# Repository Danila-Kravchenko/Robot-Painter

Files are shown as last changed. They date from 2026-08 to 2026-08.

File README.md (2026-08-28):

# Робот-художник

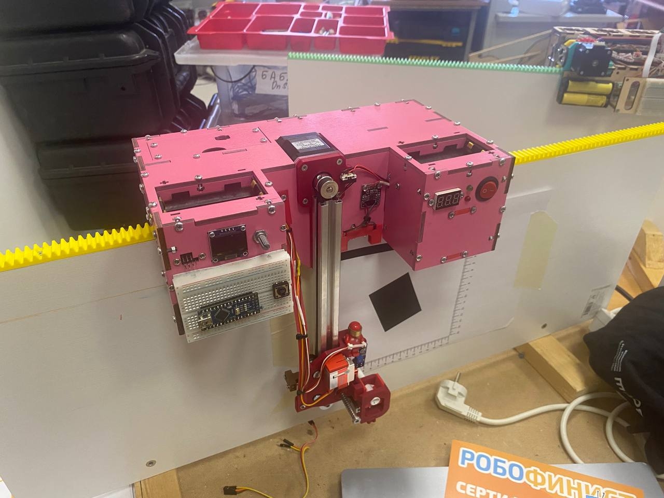
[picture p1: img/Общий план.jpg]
общий план


Робот выполнен в соответствии с **единым техническим заданием** ([ЕТЗ]("https://robot.mipt.ru/uchastnikam/reglament/etz_info/")) Всероссийской олимпиады школьников по информатике в профиле робототехника. Основые критерии ЕТЗ:
* **Задача робота** - нанесение изображений в плоскостей осей Х и У
* **Рабочая область** - лист А4, закрепленный на полигоне. Начало координат - пересечение черных линий, расположенных в левом и верхнем краях листа
* **Размеры** - 300х300х300 мм
* **Скорость** - 100 мм/с
* **Автономность** - полное отсутствие подключения внешних проводных и беспроводных компонентов
* **Погрешность позиционирования** - не более 3 мм
* **Рабочий инструмент** - маркер диаметром 8-18 мм и длиной 120-180 мм
* **Самостоятельная разработка** - запрещается использование готовые специализированных решений для 3Д-принтеров, ЧПУ-станков и т.п.
* **Интерфейс** - возможность выбирать 1 из 10 заданий, предложенных организаторами, а также наличие светодиодов индикации: зеленого и красного
* **Плата коммутации с штырьевыми разъемами:** - наличие макетной платы не менее 400 точек для подключения внешних устройств, а также разъемов с питанием 5В, интерфейсом UART, цифровыми и аналоговым входами 

---

## Аппаратная архитектура

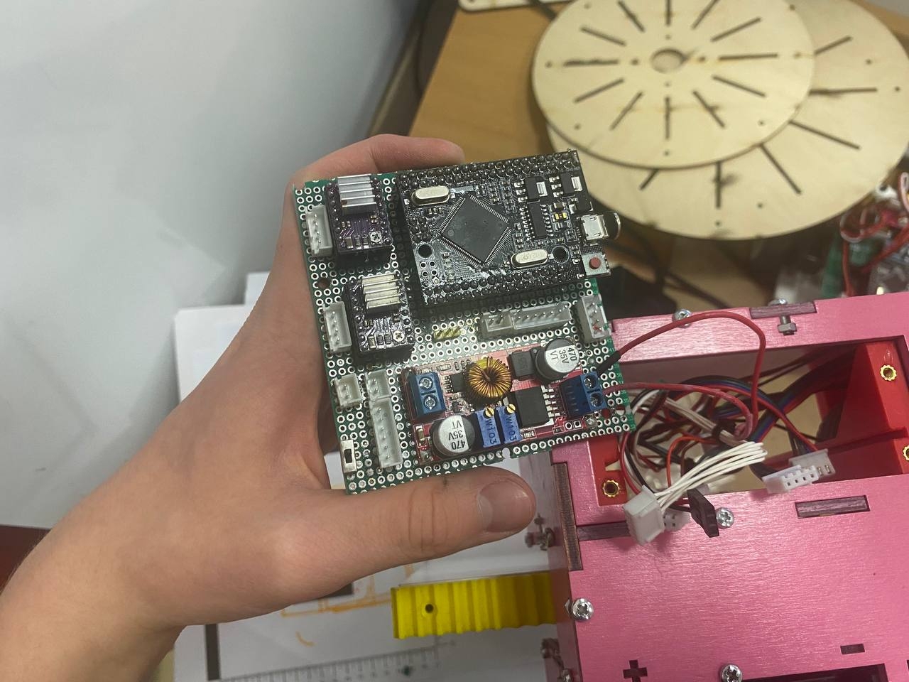
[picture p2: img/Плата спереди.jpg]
Плата спереди


### Контроллер
* Arduino Mega 2560 Pro.

### Датчики и сенсоры
* **Контроль заряда** - цифровой мультиметр 0-100В
* **Определение начала координат** - TCRT5000
* **Калибровка плоттера:**
    * Установка в 0 по У - концевой выключатель
    * Нахождение кончика маркера - ktir0911s

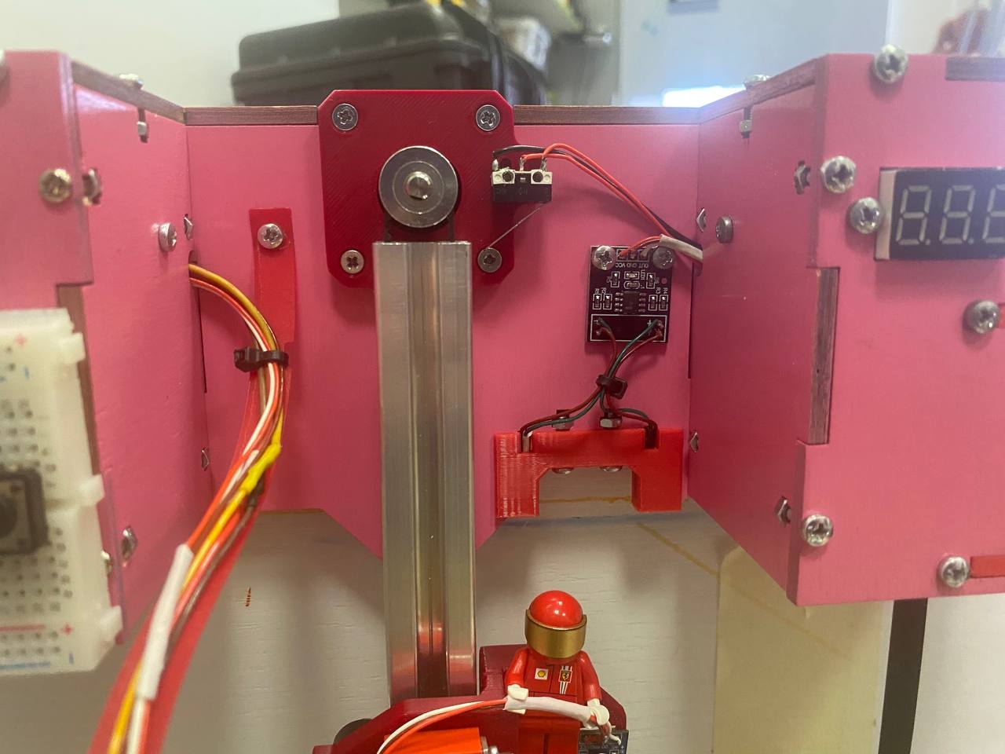
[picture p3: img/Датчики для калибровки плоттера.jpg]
Датчики для калибровки плоттера


### Интерфейс
* **Световая индикация** - красный и зеленый светодиоды
* **Отображение информации** - OLED дисплей 128х64 на чипе SSD1306
* **Выбор команды** - поворотный энкодер EC11

Интерфейс

### Разъемы
* **UART** - использование логического конвертора для подключения устройств, толерантных к 3.3В

### Исполнительные устройства
* **Моторы** 2 шаговых двигателя Nema 17 17HS8401.
* **Драйверы управления двигателями** DRV8825.
* **Плоттер** сервопривод подъёма маркера — HV2006MG;

### Система питания
* **Источник питания** - сборка 4S1P из Li-ion аккумуляторов 18650, 3000 мА·ч.
* **Распределение питания:**
    * шаговые двигатели — 16 В (напрямую от батареи);
    * сервоприводы — 7 В от стабилизатора XL4015;
    * контроллер — 16 В (напрямую от батареи) на пин Vin;
    * цифровой вольтметр — 16 В (напрямую от батареи);
    * логический конвертор - 3.3 В от пина 3.3V контроллера.
    * остальная периферия — 5 В от пина 5V контроллера.

---

## Конструкция и механика

* **Корпус** - лазерная резка из фанеры 4 мм. Сборка выполнена по системе «шип-паз» с механической фиксацией винтами.
* **Крепление к полигону** - 3 пластиковых колеса с шинами конструктора лего, а также опорная и ведущая шестерни
* **Ось У:**
    * **Плоттер:**
        * Крепление маркера - пластиковая прижамная деталь, регулируемая винтом с пластиковой накатанной головкой
        * Прижим маркера - кривошипно-кулачковый механизм для защиты от передавливания на пишущую поверхность
        
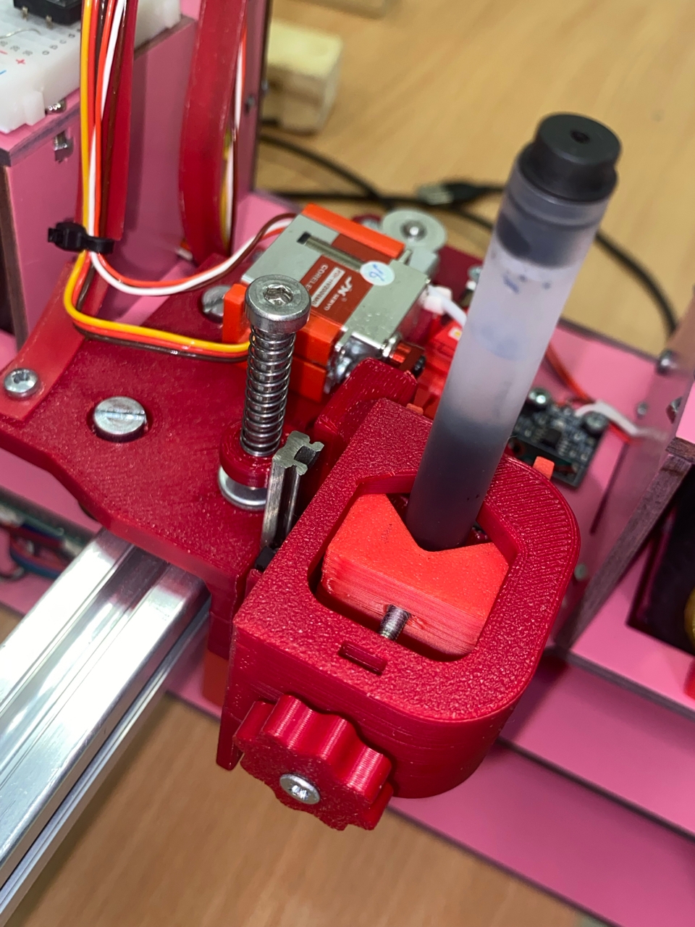
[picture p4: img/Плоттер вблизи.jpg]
Плоттер_вблизи
        

        * Крепление к V-образному профилю - 3 ролика с подвижной фиксацией
        * Крепление зубчатого ремня - подвижный фиксатор для контроля натяжения

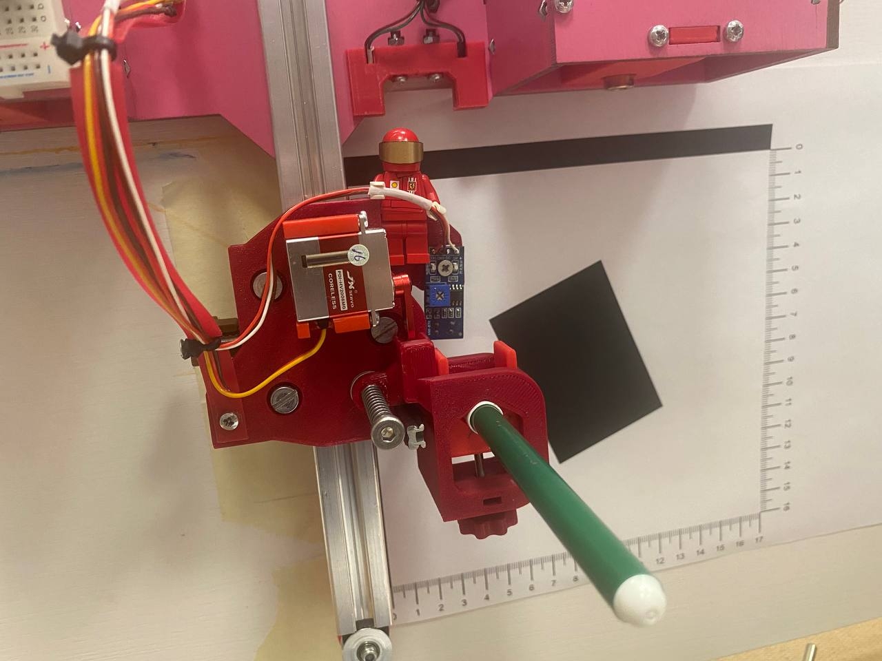
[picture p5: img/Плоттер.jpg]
Плоттер
        

    * **V-образный профиль** - перемещение плоттера
    * **Опорный ролик на профиле**
* **Выдвижная плата** - пластиковые крепления с пазами, а также съемная крышка над платой

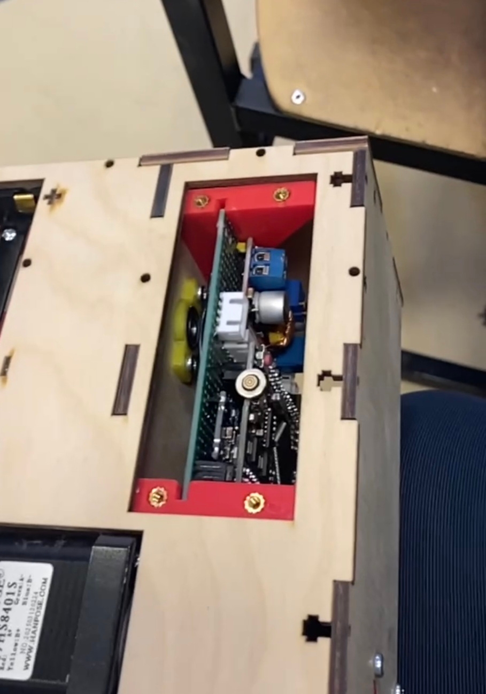
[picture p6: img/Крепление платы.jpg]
Крепление платы


---

## Алгоритмы и логика управления

В проекте реализована гибридная система траекторного управления, оптимизированная для работы с шаговыми двигателями (ШД) в координатах XY. Алгоритм разделен на два ключевых режима: линейное перемещение и криволинейное позиционирование.

### 1. Линейное перемещение

Режим предназначен для точной прорисовки прямых линий с контролируемой динамикой движения.

*   **Получение скоростей:**
    *   Результирующий вектор желаемой скорости $\vec{V}$ раскладывается на проекции по осям координат ($V_x$ и $V_y$).
    *   Для сохранения геометрии отрезка составляется жесткая пропорция скоростей на основе соотношения приращений координат:
        $$\frac{V_x}{V_y} = \frac{\Delta X}{\Delta Y}$$
    *   Расчет абсолютных значений базовых скоростей выполняется через тригонометрический базис и теорему Пифагора:
        $$V = \sqrt{V_x^2 + V_y^2}$$
*   **Защита от пропуска шагов ШД:**
    *   Интегрирован алгоритм плавного разгона и замедления (рампа скорости) с заданным предельным ускорением $a$.
    *   Во избежание перекоса осей и динамических ударов, мгновенное ускорение по каждой из осей ($a_x, a_y$) рассчитывается строго пропорционально текущей целевой скорости этой оси.
*   **Профиль скорости (Регулятор):**
    *   Реализован пропорциональный регулятор (**П-регулятор**) обратной связи по расстоянию до конечной точки.
    *   Введено ограничение управляющего воздействия (насыщение) на уровне максимальной технологической скорости ($V_{max}$).
    *   **Динамика движения:** График ускорения представляет собой наклонную прямую (линейное нарастание момента), а фаза замедления рассчитывается по экспоненциальному закону для мягкого подхода к целевой точке без перерегулирования.

### 2. Криволинейное перемещение

Режим используется для быстрого позиционирования инструмента по криволинейным траекториям.

*   **Траекторная логика:** Осуществляет перевод рабочего органа из текущей точки в заданную координату по сложной (сглаженной) траектории.
*   **Ограничение динамики:** Перемещение выполняется на фиксированной **минимальной скорости** ($V_{min}$) и **без ускорения** ($a = 0$). Такой подход гарантирует отсутствие вибраций конструкции при резкой смене направления движения инструмента во время холостых переходов.

---

## Структура ПО
* `etz_main.ino` — главный файл;
* `drivers.ino` — низкоуровневые функции управления роботом (управление моторами, перемещение в точку и т.п.);
* `move.ino` — высокоуровневые функции управления роботом (прорисовка фигур);
* `tasks.ino` — пустые функции для выполнения заданий;
* `interface.ino` — работа интерфейса: выбор задания, отображение информации о задании и т.п.;
* `ports.ino` — функции для обработки разъемов
* `hello_kitty.ino` — массив для отображения изображения

---

## Сборка и запуск

### Комплектующие и материалы

**Электронные комплектующие**

| Группа | Наименование | Модель / номинал | Кол-во | Назначение |
|---|---|---|:---:|---|
| Контроллер | Микроконтроллер | Arduino Mega 2560 Pro | 1 | Главное вычислительное ядро |
| Приводы | Шаговый двигатель | Nema 17 17HS8401 | 2 | Движение и балансировка |
| Приводы | Драйвер ШД | DRV8825 | 2 | Управление фазами ШД |
| Приводы | Сервопривод | HV2006MG | 1 | Прижим маркера |
| Сенсоры | Цифровой вольтметр | DC 0-100 V | 1 | Контроль заряда |
| Сенсоры | Концевой выключатель | 1А, 125В | 1 | Калибровка оси у |
| Сенсоры | Оптопара | TCRT5000 | 1 | Следование по линии |
| Сенсоры | Лазерный концевик | ktir0991s | 1 | Нахождение кончика маркера |
| Интерфейс | Поворотный энкодер | EC11 | 1 | Выбор режима |
| Интерфейс | Дисплей | OLED display 128x64 | 1 | Выбор режима |
| Интерфейс | Светодиоды | Красный и зеленые цвета, 5 мм | 1 | Отображение состояния |
| Разъемы | Конвертер уровней | Logic level converter 3.3V - 5V | 1 | Подключение устройств, толерантных к 3.3В |
| Питание | Аккумулятор | Li-ion 18650, 3000 мА·ч | 4 | Сборка 4S1P |
| Питание | SMD-холдер аккумуляторов | 2 × 18650 | 2 | Монтаж и коммутация АКБ |
| Питание | Тумблер | Ø 3 мм | 1 | Коммутация питания |
| Питание | DC-DC преобразователь | XL4015 | 1 | Шины 6 В |
| Обвязка | Конденсатор электролитический | 100 мкФ, 25 В | 2 | Сглаживание пульсаций по питанию драйверов |
| Обвязка | Резистор | 220 Ом | 2 | Токоограничение светодиодов |
| Монтаж | Плата макетная паячная | 9 × 15 см | 1 | Монтаж электроники |

**Механические комплектующие и материалы**

| Группа | Наименование | Модель / номинал | Кол-во | Назначение |
|---|---|---|:---:|---|
| Рама | Профиль конструкционный | 20×20 L | 1 (0,24 м) | Элемент несущей конструкции |
| Рама | Фанера берёзовая | 4 мм | — | Несущие панели рамы (лазерная резка) |
| 3D-печать | Пластик для 3D-печати | ABS / PETG / PLA | — | Колёса, плоттер, шестерни и крепежные детали |
| Механика | Миниатюрные подшипники | 5x14x5 мм | 20 шт. | Подшипниковые узлы колёс и осей |
| Механика | Муфта фланцевая жёсткая | Ø 5 мм | 2 | Соединение вала с шестернями |
| Механика | Вал линейный хромированный | Ø 5 мм, 100 мм | 4 | Опорные шестерня и колеса |
| Механика | Стопорные кольца | для втулок осей Ø 5 мм | 8 | Фиксация подшипников и втулок |
| Механика | Шкив | Perlin для Ender3 V2 | 3 | Крепление плоттера на профиле |
| Механика | Рельса и каретка | MGN7C, 50 мм | 1 | Кривошипно-кулачковы механизм |
| Механика | Пружина | 30 мм, Ø 5-8 мм | 1 | Кривошипно-кулачковы механизм |
| Механика | Зубчатый ремень | GT2-20 | 600 мм | Перемещние плоттера |
| Механика | Зубчатый шкив | GT2-20, Ø отверстия 5 мм | 1 | Перемещние плоттера |
| Механика | Зубчатый шкив с подшипником | GT2-20, Ø отверстия 5 мм, 20 зубьев | 1 | Перемещние плоттера |
| Механика | Лего шина | Артикул 41897 (56x28 мм) | 1 | Крепление к полигону |
| Крепёж | Винт М4 с неполной резьбой | М4, 5 мм - резьба; Ø 5 мм, 30 мм - нерезьбовая часть | 1 | Напрвляющая для пружины |
| Крепёж | Винты и гайки | M3 | набор | Механическая фиксация узлов |
| Крепёж | Винты и гайки | M5, 25 мм | 3 шт. | Механическая фиксация узлов |
| Крепёж | Вплавляемые гайки | M3 | набор | Механическая фиксация печатных деталей |
| Крепёж | Вплавляемые гайки | M4 | 1 шт. | Крепление винта с неполной резьбой |
| Расходники | Стяжка нейлоновая | — | набор | Кабель-менеджмент |

### Необходимое ПО
* Arduino IDE 2.0;
* библиотеки (устанавливаются через менеджер библиотек):
    * [Adafruit_SSD1306](https://github.com/adafruit/Adafruit_SSD1306.git);
    * [Adafruit_GFX](https://github.com/adafruit/Adafruit-GFX-Library.git);
    * [TimerOne](https://github.com/PaulStoffregen/TimerOne.git);
    * [TimerThree](https://github.com/PaulStoffregen/TimerThree.git).
* Скетч находится в папке `firmware/etz_main/`.

### Подключение

| Пин Arduino | Тип | Назначение | Примечание |
|---|-----|---|---|
| 4 | Цифровой | `MOTOR_DIR_Y` — направление ШД по оси у| |
| 5 | Цифровой | `MOTOR_STEP_Y` — шаг ШД по оси у | Аппаратный таймер Timer3 |
| 11 | Цифровой | `MOTOR_STEP_X` — шаг ШД по оси х | Аппаратный таймер Timer1 |
| 12 | Цифровой | `MOTOR_DIR_X` — направление ШД по оси х | |
| 9 | PWM | `CLAWS_PIN` — сервопривод клешней | |
| 2 | Цифровой | `ENCODER_PIN1` — первый канал поворотного энкодера | |
| 6 | Цифровой | `ENCODER_PIN2` — второй канал поворотного энкодера | |
| 3 | Цифровой | `BUTTON_PIN` — тактовая кнопка поворотного энкодера | |
| 27 | Цифровой | `GREEN_LED` — индикация батареи | Через резистор 220 Ом |
| 29 | Цифровой | `RED_LED` — индикация состояния | Через резистор 220 Ом |
| 25 | Цифровой | `KTIR_PIN` — лазерный концевой выключатель | нахождение кончика маркера |
| 23 | Цифровой | `END_BUTTON` — концевой выключатель | калибровка по оси у |
| 24 | Цифровой | `D_PIN` — цифровой разъем коммутационной платы | |
| A5 | Аналоговый | `A_PIN` — аналоговый разъем коммутационной платы | |
| 14 (TX3) | UART | `Serial3` — разъем-UART коммутационной платы | |
| 15 (RX3) | UART | `Serial3` — разъем-UART коммутационной платы | |
| A0 | Аналоговый | `LINE_SENSOR` — TCRT5000 | нахождение начала координат |

### Порядок запуска
1. **Инициализация:** включите робота и установите маркер в прижимной механизм на расстоянии 2-3 мм от поверхности. Нажмите кнопку на поворотном энкодере для продолжения
2. **Калибровка:** плоттер начнет определение абсолютного нуля по оси у, затем определит положение кончика маркера и сохранит знаение. После отображения интерфейса на дисплее калибровка считается законченной
3. **Определение начала координат:** единократно и автоматически запускается при выборе задачи. Для калибровки датчика света установите робота таким образом, чтобы маркер находился ровно на правой границе черной вертикальной линии. Запустите задачу `calibr` (в самом низу списка): робот откалибрует датчик освещенности и сразу определит начало координат (в дальнейшем проверок не будет)
3. **Старт:** установите указатель на дисплее на нужную задачу и нажмите на ручку поворотного энкодера 

---

## Демонстрация

Сердечко

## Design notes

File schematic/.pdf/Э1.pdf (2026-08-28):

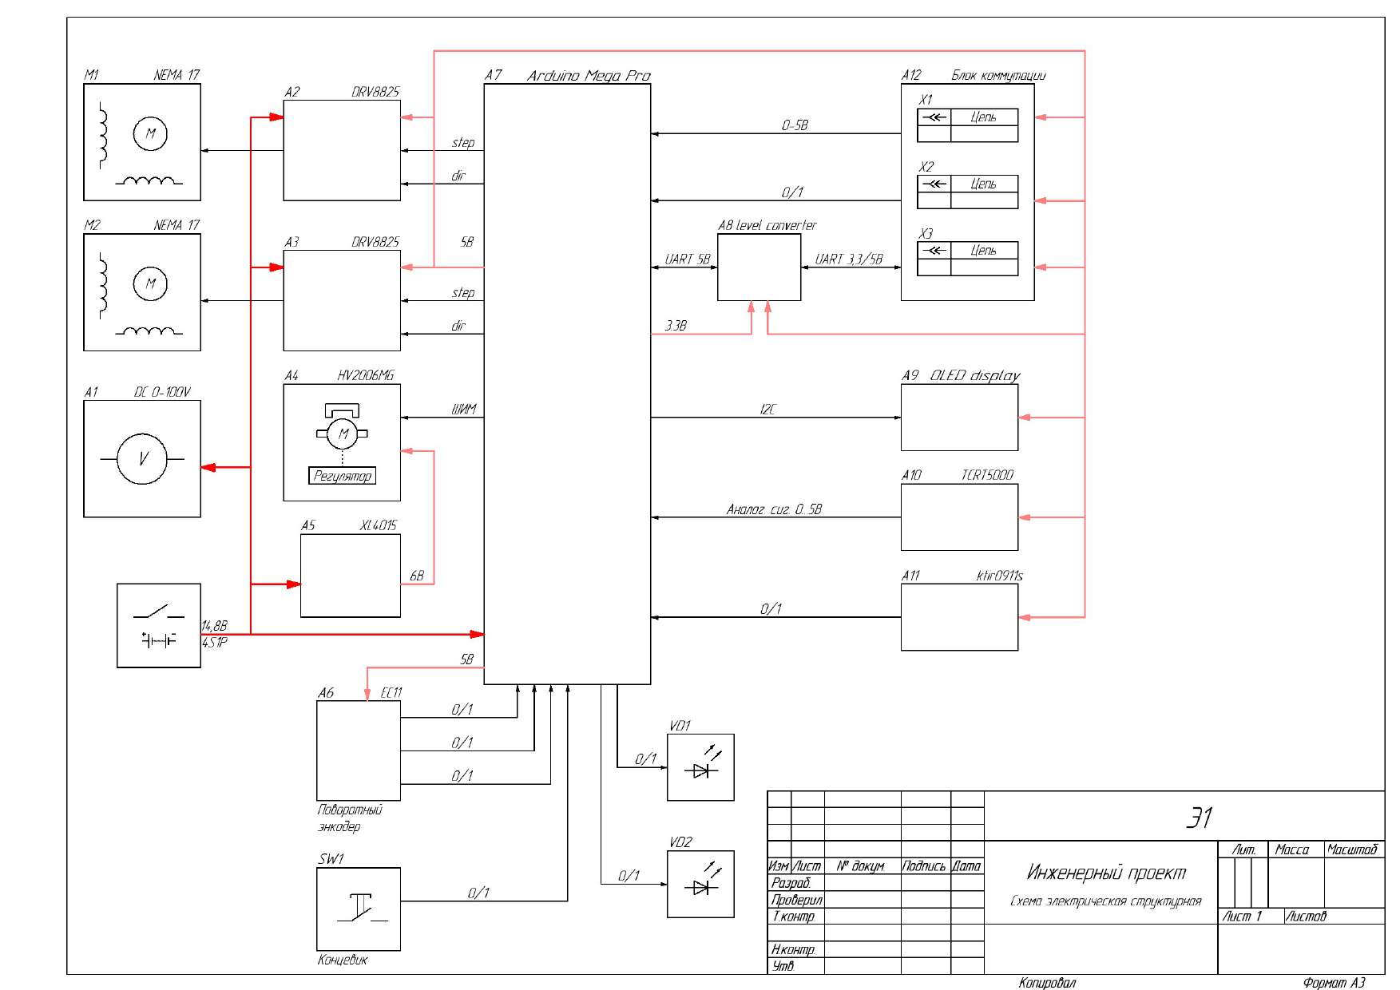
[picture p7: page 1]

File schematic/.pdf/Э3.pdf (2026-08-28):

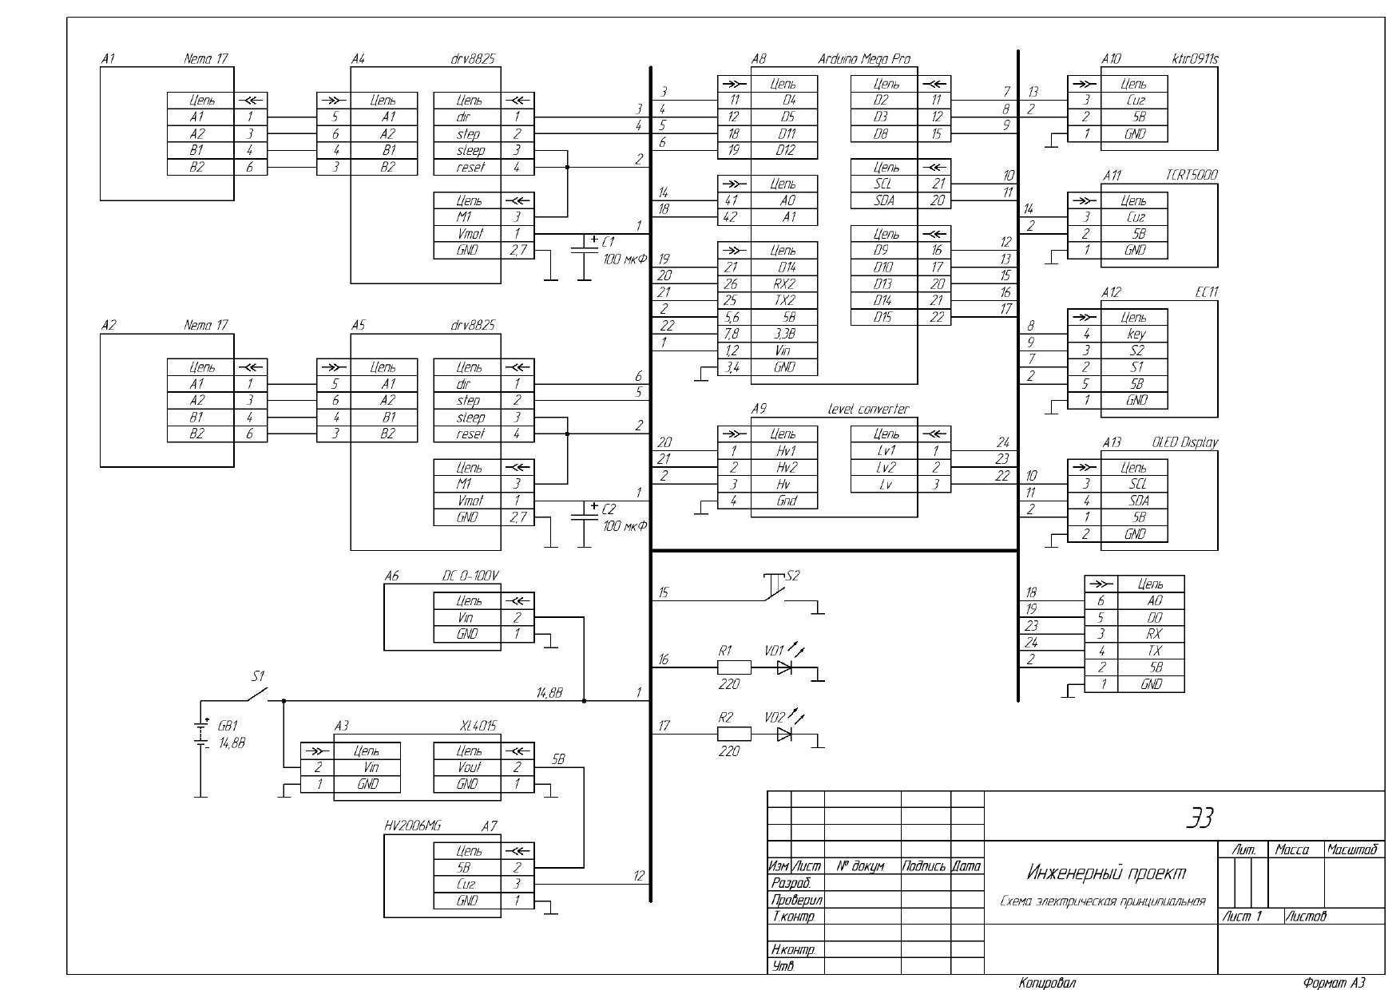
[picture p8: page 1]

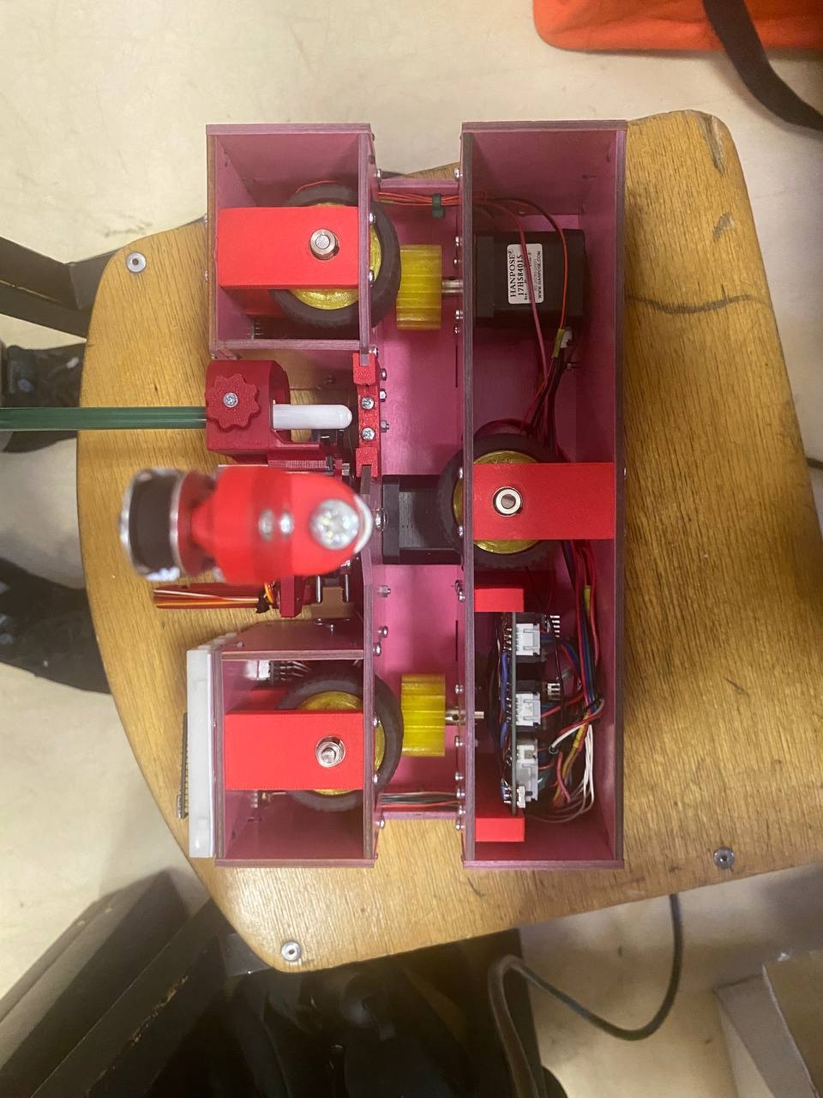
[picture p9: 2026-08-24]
img/Вид снизу.jpg

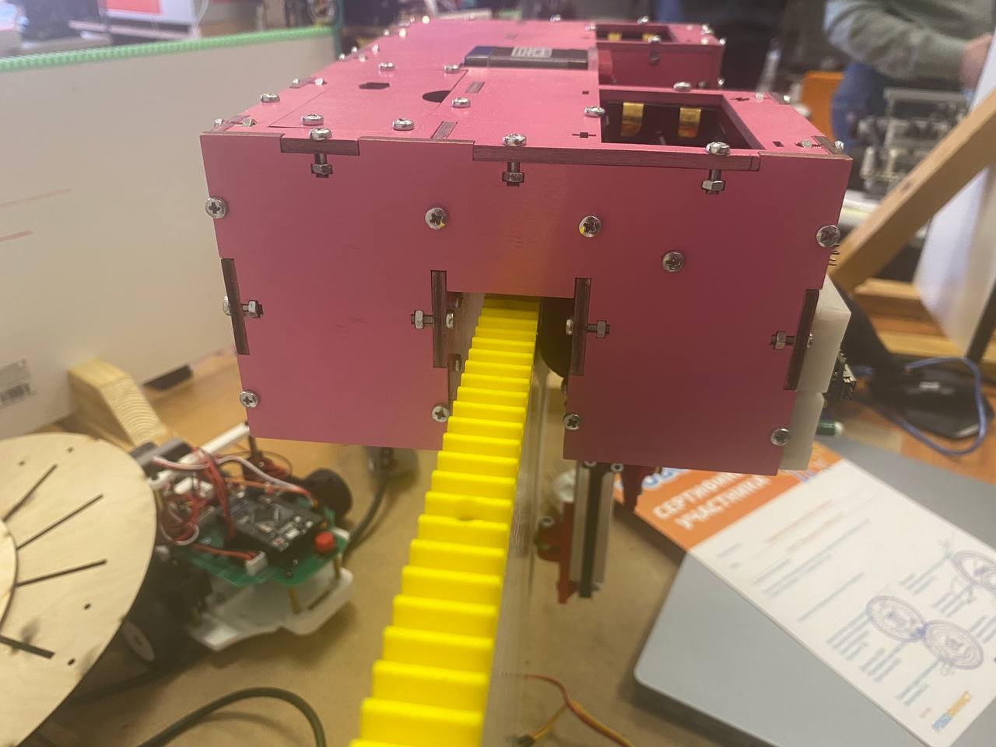
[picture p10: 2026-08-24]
img/Вид сбоку.jpg

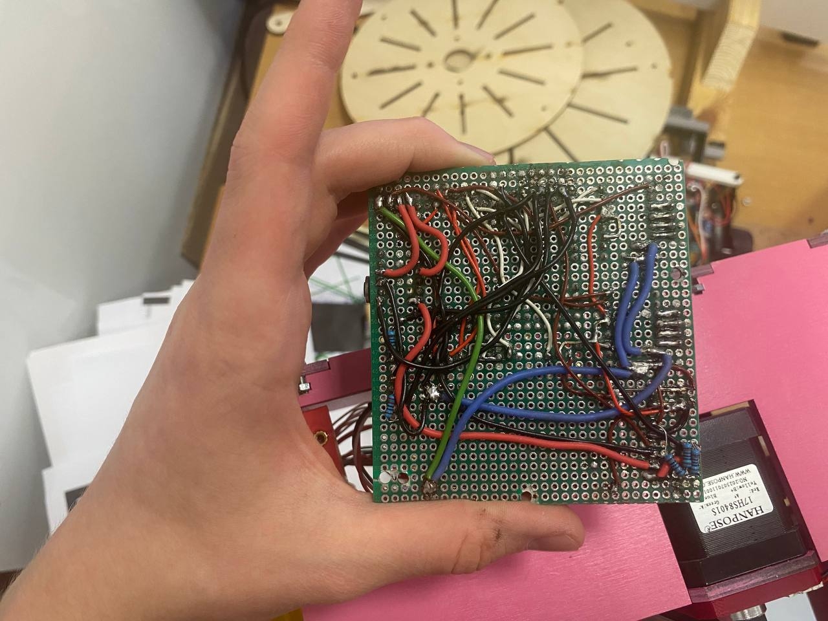
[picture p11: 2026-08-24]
img/Плата сзади.jpg

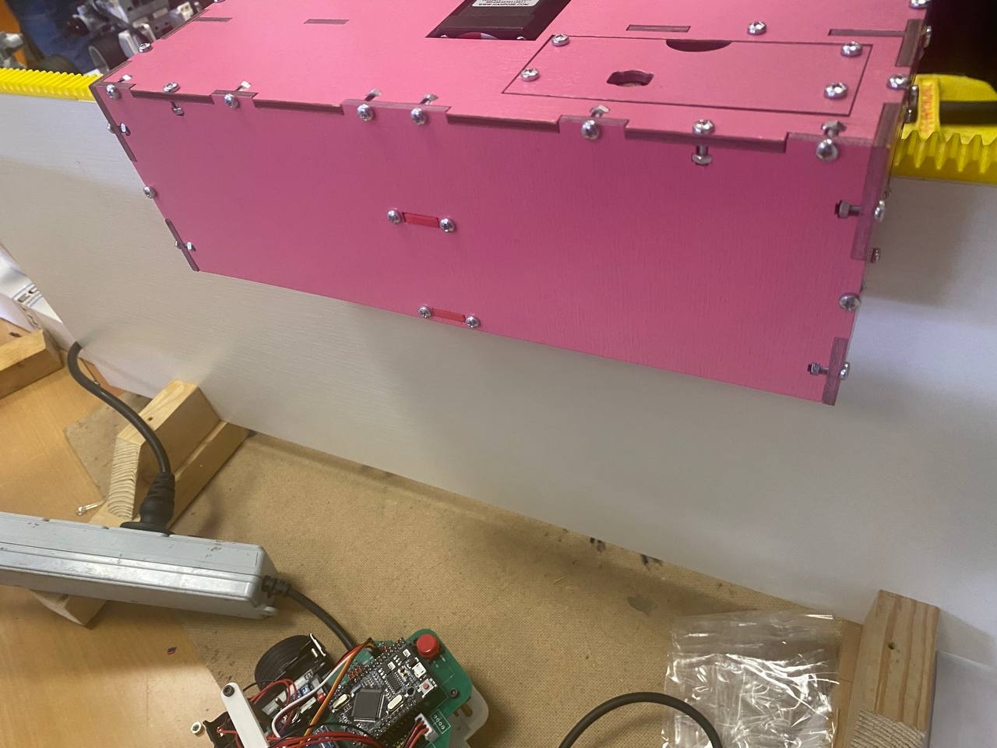
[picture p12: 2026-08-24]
img/Вид сзади.jpg

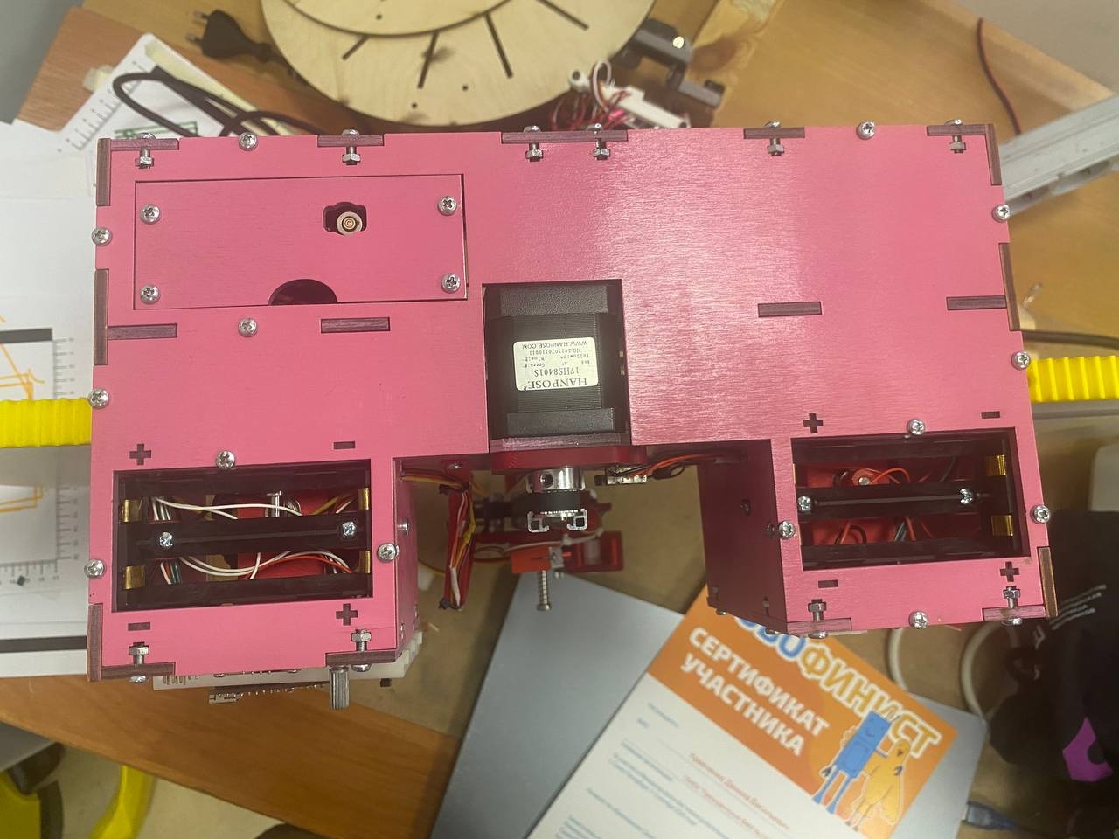
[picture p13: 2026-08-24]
img/Вид сверху.jpg

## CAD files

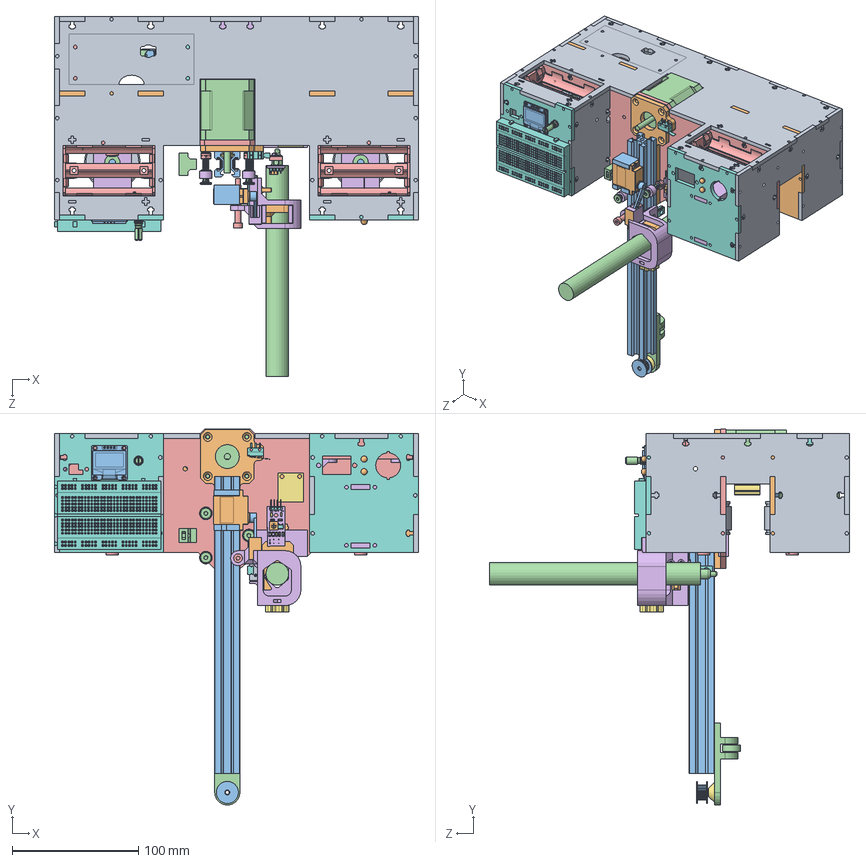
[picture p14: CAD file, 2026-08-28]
mechanics/3d model/робот_закл.SLDASM
288.0 x 297.4 x 285.0 mm
задняя стенка справа
передняя стенка справа
крепление шаговика новое
motor_17hs8401 x 2
передняя стенка слева
корпус ктира
плата под ктир
лицевая стенка
боковая правая стенка с лицевой стороны x 2
переходник для профиля
профиль
MVG-P4 x 3
MVG-P6 x 3
MVG-P3 x 3
MVG-P2 x 3
рельса
каретка для рельс
hv2006mg
Microservo horn
зажим ремня
TCRT5000
leds Geometry
pin
IC_smd_8
smd_10k Geometry x 2
cover x 2
smd_150 Geometry
cover2
Surf Geometry x 2
cover3 x 2
LED_SMD x 2
smd_1k Geometry x 2
cover4 x 2
pot Geometry
pin2
leds2 Geometry
pins
Board Geometry
TXT
4PinsOut Geometry
pin3
крепление сервы
фломастер
винт для каретки
крепление фломастера
Деталь1
концевик
колесо x 6
заглушка для колеса x 3
ось для колес x 3
подшипник x 9
стопорное кольцо x 5
крепление колес x 6
шестеренка новая x 2
втулка x 2
крепление подшипников x 2
ось для шестерни
шестерня для ремня на ось
крепление ролика
аккумуляторный отсек x 2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

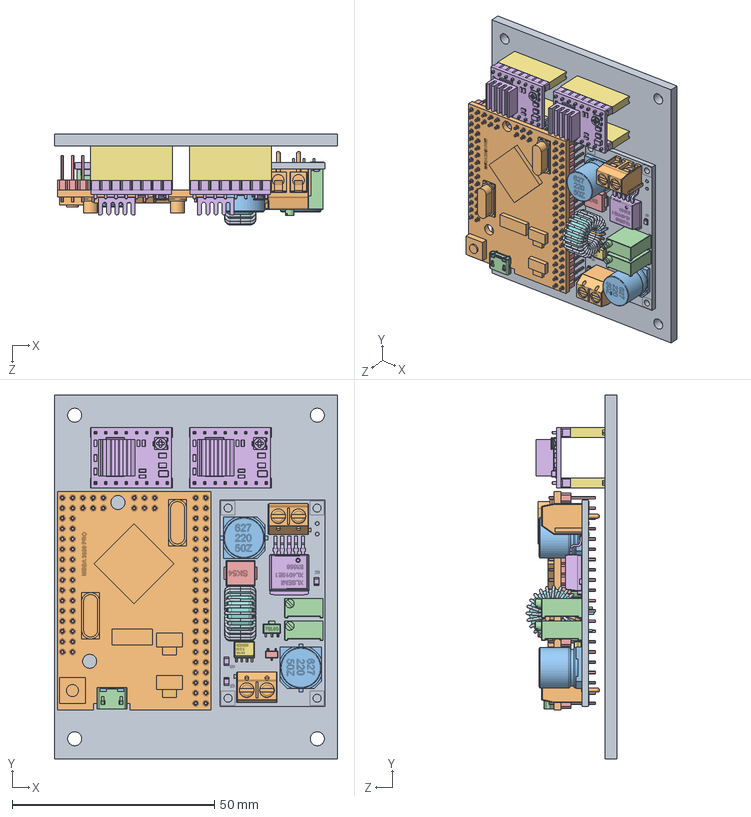
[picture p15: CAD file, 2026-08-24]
mechanics/3d model/плата.SLDASM
70.0 x 90.0 x 22.5 mm
плата
_X2_04100440043404430438043D043E_X0_ _X2_043C043504330430_X0_ __X2_0441_X0_ _X2_043D043E0436043A0430043C0438_X0_
_X2_043D043E0436043A0430_X0_ x 86
Driver DRV8825 x 2
PBS-8 x 4
kicad_module_3D_MINI560 PCB
Basetta
DG301-5.0-02 v1 x 2
CAPACITOR 10x10 SMD v1 x 2
Trimpot 3296W v1 x 2
DO-214AB v1
XL4015 TO263-5-1 v1
LM358 SOIC08 v1
Toro
Spira x 22
SpiraCodA
SpiraCpdB
UPC78L08T-E1-AZ
SC-59A v1
LED v1 x 3

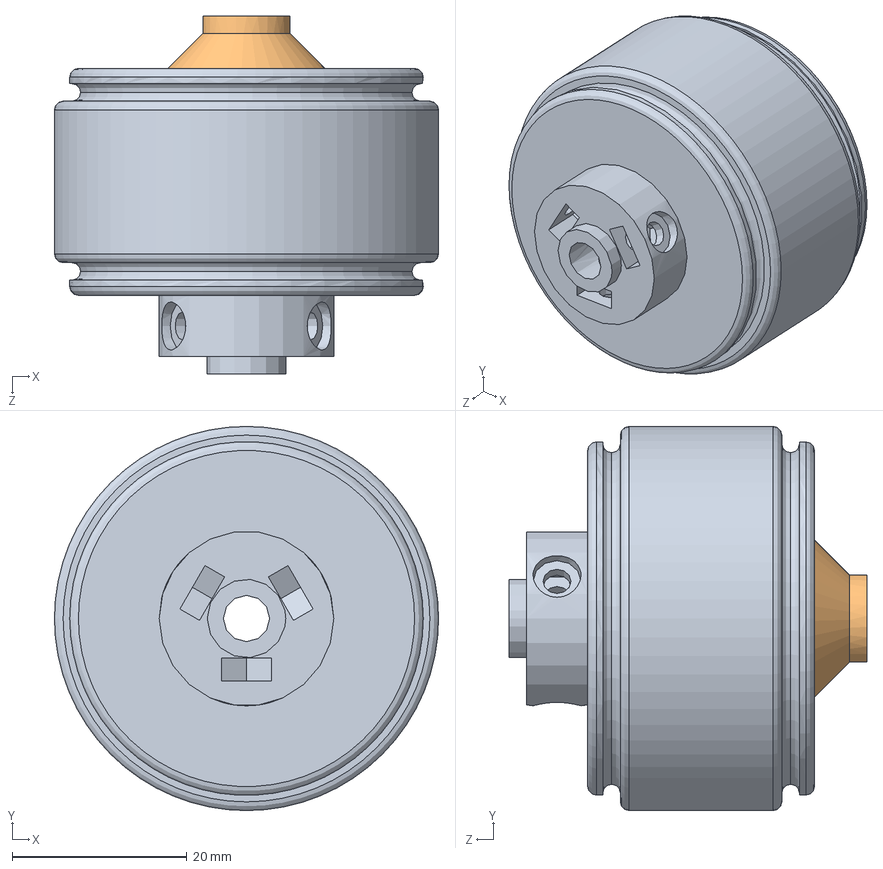
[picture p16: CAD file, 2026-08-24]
mechanics/3d model/колесо.SLDASM
44.0 x 44.0 x 41.0 mm
колесо
заглушка для колеса

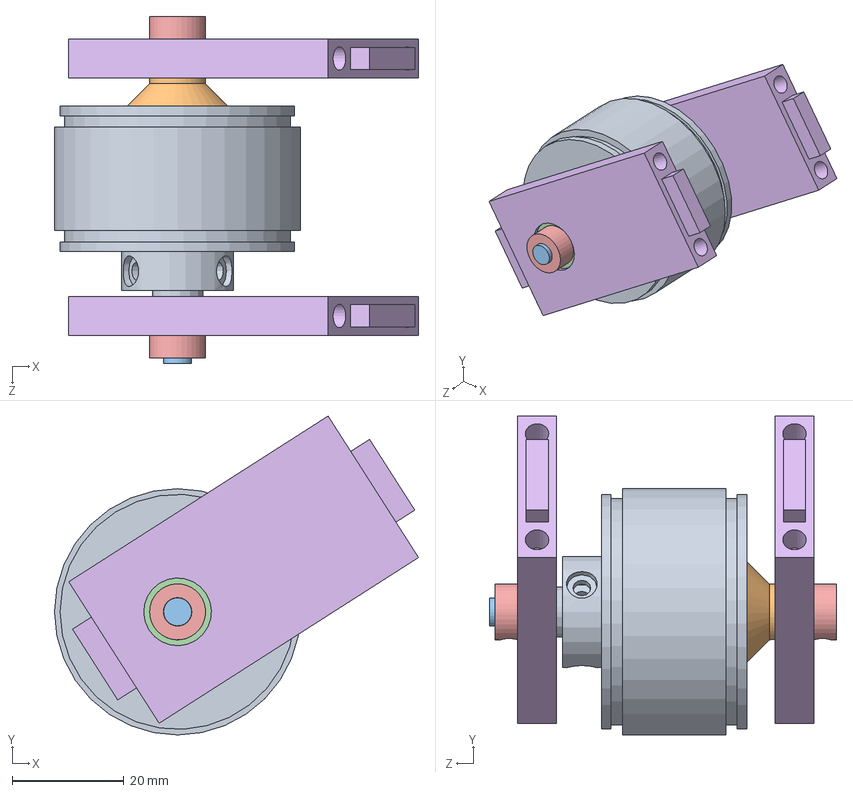
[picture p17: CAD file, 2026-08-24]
mechanics/3d model/колесо в сборе.SLDASM
65.0 x 57.0 x 62.0 mm
колесо x 2
заглушка для колеса
ось для колес
подшипник x 2
стопорное кольцо x 2
крепление колес x 2

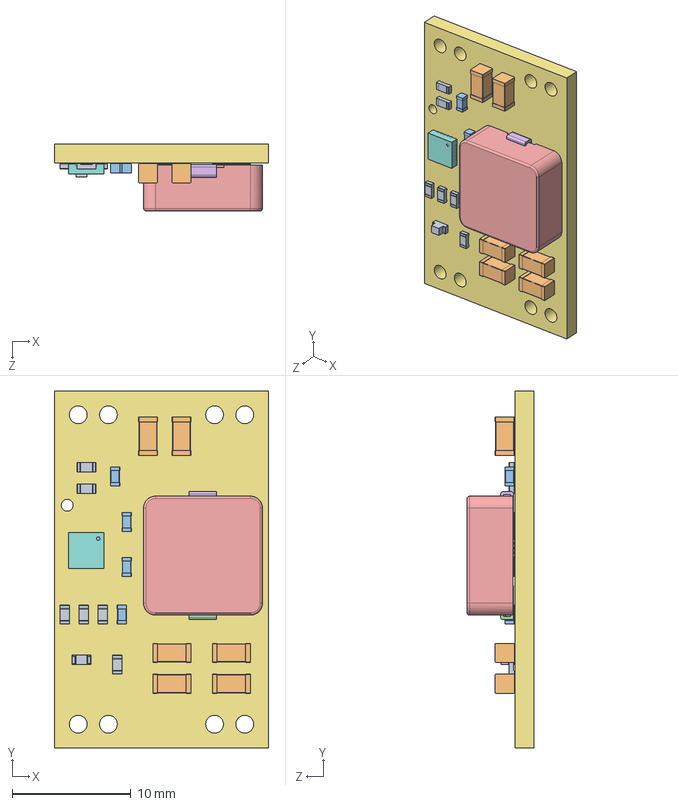
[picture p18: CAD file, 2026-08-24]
mechanics/3d model/MINI560_light.SLDASM
18.0 x 30.0 x 5.62 mm
kicad_module_3D_MINI560 PCB

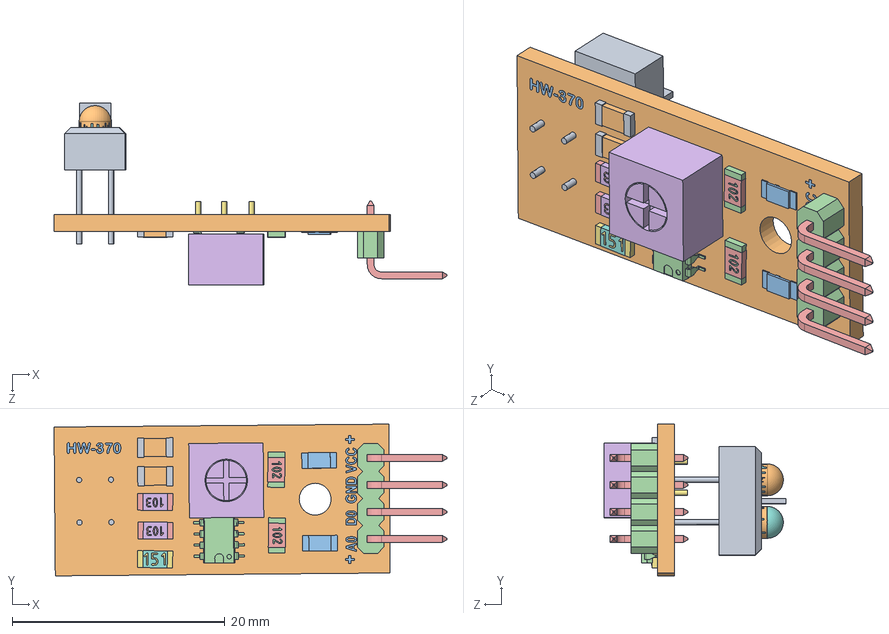
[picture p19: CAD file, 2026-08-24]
mechanics/3d model/TCRT5000.SLDASM
37.0 x 14.3 x 17.1 mm
TCRT5000
leds Geometry
pin
IC_smd_8
smd_10k Geometry x 2
cover x 2
smd_150 Geometry
cover2
Surf Geometry x 2
cover3 x 2
LED_SMD x 2
smd_1k Geometry x 2
cover4 x 2
pot Geometry
pin2
leds2 Geometry
pins
Board Geometry
TXT
4PinsOut Geometry
pin3

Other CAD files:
mechanics/3d model/pot.SLDASM
mechanics/3d model/C_0603_1608Metric.SLDASM
mechanics/3d model/Surf_2.SLDASM
mechanics/3d model/Coil v9.SLDASM
mechanics/3d model/C_1206_3216Metric.SLDASM
mechanics/3d model/smd_150.SLDASM
mechanics/3d model/R_0603_1608Metric.SLDASM
mechanics/3d model/4PinsOut.SLDASM
mechanics/3d model/MINI560.SLDASM
mechanics/3d model/Surf.SLDASM
mechanics/3d model/leds2.SLDASM
mechanics/3d model/Board.SLDASM
mechanics/.dxf/боковая правая стенка с лицевой стороны.DXF
mechanics/.dxf/боковинка.DXF
mechanics/.dxf/верхняя крышка.DXF
mechanics/.dxf/верхняя крышка_закл.DXF
mechanics/.dxf/задняя стенка справа.DXF
mechanics/.dxf/кабель.DXF
mechanics/.dxf/крепление шаговика новое.DXF
mechanics/.dxf/крепление шкива.DXF
mechanics/.dxf/крышка под плату.DXF
mechanics/.dxf/лицевая стенка.DXF
mechanics/.dxf/передняя стенка слева.DXF
mechanics/.dxf/передняя стенка справа.DXF
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

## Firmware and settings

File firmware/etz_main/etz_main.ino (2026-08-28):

#include "Wire.h"
#include <Adafruit_GFX.h>
#include <Adafruit_SSD1306.h>
#include <TimerOne.h>
#include <TimerThree.h>
#include <Servo.h>
#include <EEPROM.h>

#define MOTOR_STEP_X 11
#define MOTOR_DIR_X 10
#define MOTOR_STEP_Y 5
#define MOTOR_DIR_Y 4
#define DIST_PER_TICK_X 0.5024
#define DIST_PER_TICK_Y 0.20096
#define Ts 0.01
#define ACCEL 1750  //2273
#define V 125.0
#define V_FUNC 50.0
#define STEP_RESOLUTION 4
#define SERIAL_SPEED 9600
#define LINE_HEIGHT 1

#define IMG_WIDTH 61
#define IMG_HEIGHT 50
#define SCREEN_WIDTH 128
#define SCREEN_HEIGHT 64
#define DISPLAY_LINES 14

#define ENCODER_PIN1 2
#define ENCODER_PIN2 6
#define BUTTON_PIN 3
#define SERVO_PIN 9

#define GREEN_LED 27
#define RED_LED 29
#define KTIR_PIN 25
#define END_BUTTON 23

#define D_PIN 24
#define A_PIN A5
#define SERIAL_PIN Serial3
#define UART_SPEED 9600
#define MODE 1

#define HOME_X -150
#define LINE_SENSOR A0
#define FIND_LINE_X 75
#define FIND_LINE_Y 50
#define HANDLE_DISPLACEMENT_X -2.5
#define HANDLE_DISPLACEMENT_Y -29

Adafruit_SSD1306 display(SCREEN_WIDTH, SCREEN_HEIGHT, &Wire, 4);
Servo handle;

int current_state = 0;
bool button_pressed = false;
extern int arrow_pos;

uint32_t line_value = EEPROM.read(0) * 4;
double handle_displacement = EEPROM.read(1);
double home_y = 10;

volatile int step_x = 0, step_y = 0, dir_x = 1, dir_y = 1;
volatile double Vx = 0, Vy = 0, Vlim_x, Vlim_y, x_curr = HOME_X, y_curr = 0, ax, ay;
volatile bool step_state_x = false, step_state_y = false, hanlde_calibrated = false;

bool in_home = true, line_y_found = false;

void setup() {
  init_interface();
  init_serial();
  init_servo();
  init_led();
  init_ktir();
  init_end_button();
  init_motors();
  init_pin_A();
  init_pin_D(MODE);
  init_pin_UART();

  set_handle();
  set_zero_y();
}
void loop() {
  show_interface();
  set_task();
}

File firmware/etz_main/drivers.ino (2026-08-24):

int top = 130, bottom = 180, mid = 155;
bool handle_is_down = true;

void init_motors() {
  pinMode(MOTOR_DIR_X, OUTPUT);
  pinMode(MOTOR_STEP_X, OUTPUT);
  pinMode(MOTOR_DIR_Y, OUTPUT);
  pinMode(MOTOR_STEP_Y, OUTPUT);

  Timer1.initialize(1000);
  Timer1.attachInterrupt(ISR_X);
  Timer1.stop();

  Timer3.initialize(1000);
  Timer3.attachInterrupt(ISR_Y);
  Timer3.stop();
}
void init_servo() {
  handle.attach(SERVO_PIN);
  up_handle();
}
void init_serial() {
  Serial.begin(SERIAL_SPEED);
}

void ISR_X() {
  digitalWrite(MOTOR_STEP_X, step_state_x);
  digitalWrite(MOTOR_DIR_X, dir_x == 1 ? 1 : 0);
  x_curr += dir_x * step_state_x * DIST_PER_TICK_X / STEP_RESOLUTION;

  step_state_x = 1 - step_state_x;
}
void ISR_Y() {
  digitalWrite(MOTOR_STEP_Y, step_state_y);
  digitalWrite(MOTOR_DIR_Y, dir_y == 1 ? 1 : 0);
  y_curr += dir_y * step_state_y * DIST_PER_TICK_Y / STEP_RESOLUTION;

  step_state_y = 1 - step_state_y;
}

void motor(double speed_x, double speed_y) {
  static volatile double speed_x_last = 0, speed_y_last = 0;

  if (abs(speed_x) > DIST_PER_TICK_X / STEP_RESOLUTION) {
    if (speed_x > 0) dir_x = 1;
    else dir_x = -1;

    speed_x = abs(speed_x);
    speed_x = constrain(speed_x, 0, V);
    speed_x = 1000000 * DIST_PER_TICK_X / speed_x / 2 / STEP_RESOLUTION;

    if (speed_x_last != speed_x) {
      Timer1.setPeriod(speed_x);
      Timer1.start();
    }

    in_home = false;
  } else {
    Timer1.stop();
  }
  speed_x_last = speed_x;

  if (abs(speed_y) > DIST_PER_TICK_Y / STEP_RESOLUTION) {
    if (speed_y > 0) dir_y = 1;
    else dir_y = -1;

    speed_y = abs(speed_y);
    speed_y = constrain(speed_y, 0, V);
    speed_y = 1000000 * DIST_PER_TICK_Y / speed_y / 2 / STEP_RESOLUTION;

    if (speed_y_last != speed_y) {
      Timer3.setPeriod(speed_y);
      Timer3.start();
    }

    in_home = false;
  } else {
    Timer3.stop();
  }
  speed_y_last = speed_y;
}
void stop_motor() {
  motor(0, 0);
  delay(200);
  Vx = 0;
  Vy = 0;
}

double acceleration(double V_curr, double V_wish, double accel) {
  static double err;
  err = V_wish - V_curr;
  return min(accel * Ts, abs(err)) * sign(err);
}
int sign(double input) {
  if (input >= 0) return 1;
  else return -1;
}
void wait() {
  static uint32_t wait_timer;
  wait_timer = micros();
  while (micros() - wait_timer < Ts * 1000000) motor(Vx, Vy);
}
double dist_to_point(double x1, double y1, double x2 = x_curr, double y2 = y_curr) {
  return sqrt((x1 - x2) * (x1 - x2) + (y1 - y2) * (y1 - y2));
}
/*double get_angle(double size_x, double size_y){
  return atan(size_y / size_x) / PI * 180;
}*/
double get_line_sens_pos_x(bool move_left=false) {
  Serial.println(x_curr - HANDLE_DISPLACEMENT_X - 4 * move_left);
  return x_curr - HANDLE_DISPLACEMENT_X - 4 * move_left;
}
double get_line_sens_pos_y(bool move_up=false) {
  Serial.println(y_curr - handle_displacement - 11.5 - 10 * move_up);
  return y_curr - handle_displacement - 11.5 - 10 * move_up;
}
void set_pos(double x, double y) {
  static double dS_x, dS_y, k, err_x, err_y, Vx_wish, Vy_wish;

  x = constrain(x, HOME_X, 280);
  y = constrain(y, 0, 170);

  dS_x = x - x_curr;
  dS_y = y - y_curr;
  //stop_motor();
  if (abs(dS_x) < 0.15) {
    k = 0;
    Vlim_y = V * sign(dS_y);
    Vlim_x = 0;
    ay = ACCEL;
    ax = 0;
  } else {
    k = abs(dS_y / dS_x);
    Vlim_x = V * sqrt(k * k + 1) / (k * k + 1) * sign(dS_x);
    Vlim_y = abs(Vlim_x) * k * sign(dS_y);
    ax = ACCEL * sqrt(k * k + 1) / (k * k + 1);
    ay = ax * k;
  }

  while (((x - x_curr) * sign(dS_x) > 0.25 || (y - y_curr) * sign(dS_y) > 0.25)) {
    err_x = (x - x_curr) * 15.5 + Vlim_x * 0.1;
    Vx_wish = min(abs(Vlim_x), abs(err_x)) * sign(dS_x);
    err_y = (y - y_curr) * 15.5 + Vlim_y * 0.1;
    Vy_wish = min(abs(Vlim_y), abs(err_y)) * sign(dS_y);

    Vx += acceleration(Vx, Vx_wish, ax);
    Vy += acceleration(Vy, Vy_wish, ay);
    wait();
  }
  stop_motor();
}
void set_pos_func(double x, double y) {
  static double dS_x, dS_y, k;

  x = constrain(x, HOME_X, 280);
  y = constrain(y, 0, 170);

  dS_x = x - x_curr;
  dS_y = y - y_curr;
  if (abs(dS_x) < 0.05) {
    k = 0;
    Vlim_y = V_FUNC * sign(dS_y);
    Vlim_x = 0;
  } else {
    k = abs(dS_y / dS_x);
    Vlim_x = V_FUNC * sqrt(k * k + 1) / (k * k + 1) * sign(dS_x);
    Vlim_y = abs(Vlim_x) * k * sign(dS_y);
  }
  Vx = Vlim_x;
  Vy = Vlim_y;

  while (((x - x_curr) * sign(dS_x) > 0.35 || (y - y_curr) * sign(dS_y) > 0.35)) {
    wait();
  }
}
void set_pos_line_sens(double x, double y) {
  set_pos(x + HANDLE_DISPLACEMENT_X, y + handle_displacement + 9.5);
}
void move(double dS_x, double dS_y) {
  set_pos(x_curr + dS_x, y_curr + dS_y);
}

void up_handle() {
  if (!handle_is_down) return;

  handle_is_down = false;
  handle.write(top);
  stop_motor();
}
void down_handle() {
  if (handle_is_down) return;

  handle_is_down = true;
  handle.write(bottom);
  stop_motor();
}
void set_handle() {
  delay(125);
  handle_is_down = true;
  while (!button_pressed) handle.write(mid);
  up_handle();
  button_pressed = false;
  hanlde_calibrated = true;
}
void init_led() {
  pinMode(RED_LED, OUTPUT);
  pinMode(GREEN_LED, OUTPUT);

  digitalWrite(RED_LED, HIGH);
  digitalWrite(GREEN_LED, HIGH);
}
void light(bool led_state) {
  digitalWrite(RED_LED, led_state);
}

void init_ktir() {
  pinMode(KTIR_PIN, INPUT_PULLUP);
}
void init_end_button() {
  pinMode(END_BUTTON, INPUT_PULLUP);
}

void calibr() {
  static const int sensor_reading = 100;

  // калибровка датчика света
  x_curr = 0;
  set_pos(0, FIND_LINE_X);
  line_value = 0;
  for (int times = 0; times < sensor_reading; times++) {
    line_value += analogRead(LINE_SENSOR);
    delay(10);
  }
  line_value /= sensor_reading;
  EEPROM.write(0, line_value / 4);

  //нахождение 0 по у
  while (!digitalRead(END_BUTTON)) {
    Vy = -40;
    wait();
  }
  y_curr = 0;

  //определение смещения маркера
  move(0, 30);
  handle.write(mid);
  delay(500);
  handle_is_down = true;
  while (!digitalRead(KTIR_PIN)) {
    Vy = -5;
    wait();
  }
  stop_motor();
  handle_displacement = y_curr;
  Serial.println(handle_displacement);
  EEPROM.write(1, (int)handle_displacement);

  //нахождение линии по у
  move(20, FIND_LINE_Y);
  while (analogRead(LINE_SENSOR) < line_value * 0.65) {
    Vy = -7.5;
    wait();
  }
  line_y_found = true;
  stop_motor();
  move(0, HANDLE_DISPLACEMENT_Y + handle_displacement);
  up_handle();

  home_y = y_curr;
  EEPROM.write(2, (int)home_y);
  y_curr = 0;

  //установка домой
  set_pos(HOME_X, 0);
  in_home = true;
  current_state = 0;
  arrow_pos = 0;
}
void set_zero_y() {
  while (!digitalRead(END_BUTTON)) {
    Vy = -20;
    wait();
  }
  y_curr = 0;
  set_pos(HOME_X, home_y);
}

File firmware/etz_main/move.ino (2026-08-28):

void home() {
  if (in_home) return;

  handle_is_down = true;
  up_handle();
  set_pos(HOME_X, 0);
  in_home = true;
}
void find_line() {
  //по х
  set_pos(HOME_X, FIND_LINE_X);
  while (analogRead(LINE_SENSOR) < line_value) {
    Vx = 75;
    wait();
  }
  motor(60, 0);
  delay(300);
  while (analogRead(LINE_SENSOR) < line_value) {
    Vx = -10;
    wait();
  }
  x_curr = 0;
  stop_motor();

  //по у
  if (!line_y_found) {
    set_pos(15, FIND_LINE_Y);
    while (analogRead(LINE_SENSOR) < line_value * 0.65) {
      Vy = -7.5;
      wait();
    }
    line_y_found = true;
    stop_motor();
    move(0, HANDLE_DISPLACEMENT_Y + handle_displacement);
    up_handle();

    home_y = y_curr;
    EEPROM.write(2, (int)home_y);
    y_curr = 0;
    line_y_found = true;
  }
}
void draw_point(double start_x, double start_y) {
  up_handle();
  set_pos(start_x, start_y);
  down_handle();
  delay(200);
  up_handle();
}
void draw_line(double start_x, double start_y, double end_x, double end_y) {
  if (dist_to_point(start_x, start_y) > 1) {
    up_handle();
    set_pos(start_x, start_y);
  }
  down_handle();
  set_pos(end_x, end_y);
  up_handle();
}
void draw_many_lines(double end_x, double end_y, double start_x = -1, double start_y = -1) {
  static double last_x = 0, last_y = 0;

  if (start_x == -1) start_x = last_x;
  if (start_y == -1) start_y = last_y;

  if (dist_to_point(start_x, start_y) > 1) {
    up_handle();
    set_pos(start_x, start_y);
  }
  down_handle();
  set_pos(end_x, end_y);

  last_x = end_x;
  last_y = end_y;
}
void draw_dS_line(double start_dS_x, double start_dS_y, double dS_x, double dS_y) {
  up_handle();
  move(start_dS_x + sign(dS_x) * LINE_HEIGHT, start_dS_y + sign(dS_y) * LINE_HEIGHT);
  down_handle();
  move(dS_x - sign(dS_x) * LINE_HEIGHT, dS_y - sign(dS_y) * LINE_HEIGHT);
  up_handle();
}
void draw_length_line(double start_length, double start_angle, double length, double angle) {
  angle = angle / 180 * PI;
  start_angle = start_angle / 180 * PI;
  up_handle();
  move(start_length * cos(angle), start_length * sin(angle));
  down_handle();
  move(length * cos(angle), length * sin(angle));
  up_handle();
}
void draw_rect(double start_x, double start_y, double width, double height, double angle = 0) {
  angle = angle * PI / 180;
  draw_many_lines(start_x + width * cos(angle), start_y + width * sin(angle), start_x, start_y);
  draw_many_lines(start_x + width * cos(angle) + height * sin(angle), start_y + width * sin(angle) + height * cos(angle));
  draw_many_lines(start_x + height * sin(angle), start_y + height * cos(angle));
  draw_many_lines(start_x, start_y);
  up_handle();
}
void draw_triangle(double apex1_x, double apex1_y, double apex2_x, double apex2_y, double apex3_x, double apex3_y) {
  draw_many_lines(apex2_x, apex2_y, apex1_x, apex1_y);
  draw_many_lines(apex3_x, apex3_y);
  draw_many_lines(apex1_x, apex1_y);
  up_handle();
}
void draw_circle(double x_center, double y_center, double R, bool point = 0, double k = 1) {
  static double x_new, y_new;
  static double a = R / sqrt(k), b = R, length = PI * (3 * (a + b) - sqrt((3 * a + b) * (a + 3 * b)));  // Приближённая формула Рамануджана
  static int n = length / 2.5;

  if (point) draw_point(x_center, y_center);
  x_new = x_center + cos(PI) * R * k;
  y_new = y_center + sin(PI) * R;
  set_pos(x_new, y_new);
  down_handle();

  for (int i = 1; i <= n * 2; i++) {
    x_new = x_center + cos(PI / n * i + PI) * R * k;
    y_new = y_center + sin(PI / n * i + PI) * R;
    set_pos_func(x_new, y_new);
  }
  stop_motor();
  up_handle();
  set_pos(x_center, y_center);
}
/*
void draw_function(double center_x, double center_y, double scale = 1) {
  static double const_part, changing_part;
  static double radius = 5;
  static bool start;
  start = false;
  changing_part = -1;

  for (double x = -sqrt(radius); x < sqrt(radius); x += 0.05) {
    const_part = pow(x * x, 1.0 / 3);
    changing_part = sqrt(radius - x * x);
    if (!start) {
      set_pos(center_x + x * scale, center_y - (const_part + changing_part) * scale);
      down_handle();
      start = true;
    } else {
      set_pos_func(center_x + x * scale, center_y - (const_part + changing_part) * scale);
    }
  }

  if (changing_part == -1) return;

  for (double x = sqrt(radius); x > -sqrt(radius); x -= 0.05) {
    const_part = cbrt(x * x);
    changing_part = -sqrt(radius - x * x);
    set_pos_func(center_x + x * scale, center_y - (const_part + changing_part) * scale);
  }
  up_handle();
} /*
void draw_function(double center_x, double center_y, double scale = 1) {
  static double const_part, changing_part;
  static double radius = 5;
  static bool start;
  start = false;
  changing_part = -1;

  for (double x = -1; x < 1; x += 0.025) {
    const_part = 0;
    changing_part = sqrt((-2 * x * x - 1 + sqrt(8 * x * x + 1)) / 2);
    if (!start) {
      set_pos(center_x + x * scale, center_y - (const_part + changing_part) * scale);
      down_handle();
      start = true;
    } else {
      set_pos_func(center_x + x * scale, center_y - (const_part + changing_part) * scale);
    }
  }

  //if (changing_part == -1) return;

  for (double x = 1; x > -1; x -= 0.025) {
    const_part = 0;
    changing_part = -sqrt((-2 * x * x - 1 + sqrt(8 * x * x + 1)) / 2);
    set_pos_func(center_x + x * scale, center_y - (const_part + changing_part) * scale);
  }
  up_handle();
}*/

void find_point(int dir, double &center_x, double &center_y, double k = 0.3) {
  static double top, bottom, left, right;
  //нахождение середины по х
  //set_pos(x_curr, (bottom + top) / 2);
  move(3 * dir, 0);
  while (analogRead(LINE_SENSOR) > line_value * k) {
    Vx = 10 * dir;
    wait();
  }
  left = x_curr;
  stop_motor();
  move(-3 * dir, 0);
  while (analogRead(LINE_SENSOR) > line_value * k) {
    Vx = -10 * dir;
    wait();
  }
  stop_motor();
  right = x_curr;
  center_x = (left + right) / 2 + HANDLE_DISPLACEMENT_X /* * (dir == 1)*/;

  //нахождение середины по у
  set_pos((right + left) / 2, y_curr);
  move(0, 10);
  while (analogRead(LINE_SENSOR) < line_value * k) {
    Vy = -5;
    wait();
  }
  move(0, -3);
  while (analogRead(LINE_SENSOR) > line_value * k) {
    Vy = -5;
    wait();
  }
  top = y_curr;
  stop_motor();
  move(0, 5.5);
  while (analogRead(LINE_SENSOR) > line_value * k) {
    Vy = 5;
    wait();
  }
  bottom = y_curr;
  center_y = (bottom + top) / 2 + HANDLE_DISPLACEMENT_Y + handle_displacement + 3.5;

  set_pos((right + left) / 2, (bottom + top) / 2);
}

void test() {
  find_line();

  draw_many_lines(5, 5, 5, 155);
  draw_many_lines(155, 5);

  home();
}

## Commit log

2026-08-24 Add all files
    [10x10mm.SLDASM, 4PinsOut Geometry.SLDPRT, 4PinsOut.SLDASM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]
2026-08-28 version 1.0
    [крепление платы левое.SLDPRT, крепление платы правое.SLDPRT, робот_закл.SLDASM]
